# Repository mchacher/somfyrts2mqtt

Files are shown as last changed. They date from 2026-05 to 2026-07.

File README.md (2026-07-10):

# somfyrts2mqtt

A Somfy RTS to MQTT bridge running on an ESP32 + CC1101 transceiver. Plug it on your LAN, configure it once via a captive portal, and your Somfy RTS shutters and awnings become controllable from any MQTT-aware home automation system.

The MQTT layer follows the [Tasmota Shutter convention](https://tasmota.github.io/docs/Blinds-and-Shutters/) — `cmnd/<root>/<name>/{Open,Close,Stop,Position,…}` topics, `tele/<root>/SENSOR` aggregated telemetry, `tele/<root>/LWT` retained presence. Any client that already speaks Tasmota integrates out of the box :

- **[Sowel](https://docs.sowel.org)** via the [`sowel-plugin-somfy-rts`](https://github.com/mchacher/sowel-plugin-somfy-rts) plugin — the original target ; this bridge is a companion device for the Sowel home-automation engine
- **[Home Assistant](https://www.home-assistant.io/integrations/mqtt/)** via the MQTT Cover integration (see the sample YAML in [docs/mqtt-api.md](docs/mqtt-api.md#home-assistant))
- **OpenHAB**, **Node-RED**, **mosquitto_pub**, or any custom MQTT client

The bridge stays a "dumb" RF transponder à la Zigbee2MQTT : every home-automation rule lives upstream.

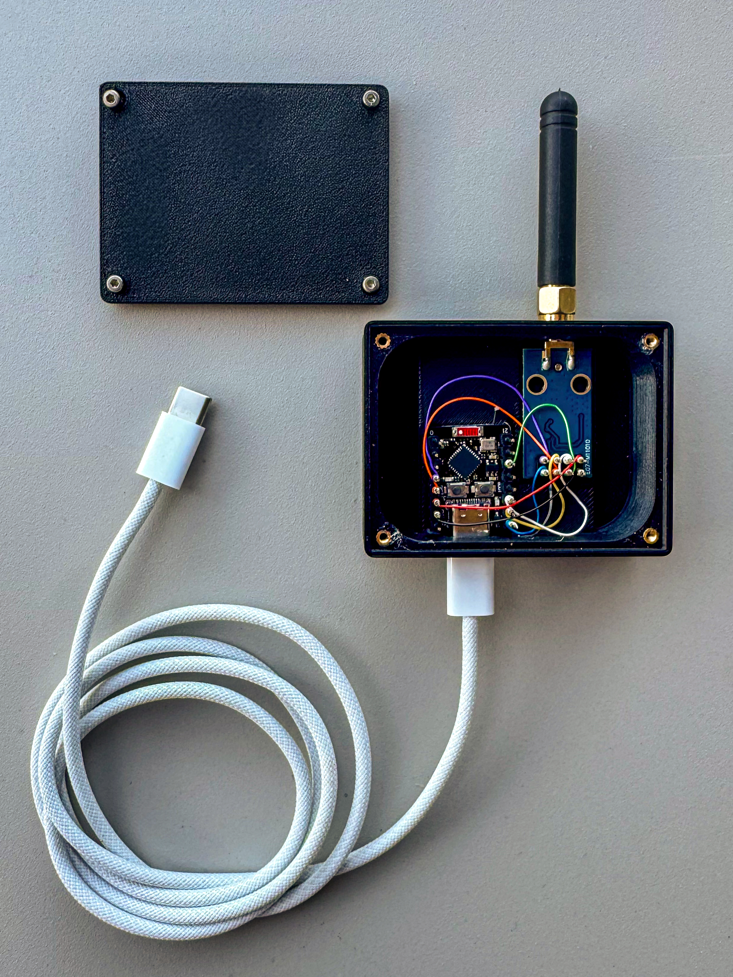
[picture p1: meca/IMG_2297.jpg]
Assembled device


The reference hardware is an ESP32-C3 Super Mini + CC1101 module wired together in a 3D-printed housing (FreeCAD source + STLs in [`meca/`](meca/)). Total cost ~10 €. The 7-wire ESP32 ↔ CC1101 interconnect can be done with regular soldering or with **30 AWG wire-wrap** — we strongly prefer wire-wrap for this kind of compact, point-to-point job : tighter, lower impedance, no rosin mess, and the connection looks far cleaner inside the housing. See [`meca/README.md`](meca/README.md#interconnect--wire-wrapping-recommended) for the why and the tool list, and [docs/hardware.md](docs/hardware.md) for the BoM and the pinout. If you would rather not solder anything, the firmware also supports the off-the-shelf **ESP32-S3 PICYBI Radio Remote** board (CC1101 already wired) — flash its `esp32-s3-picybi` binary instead.

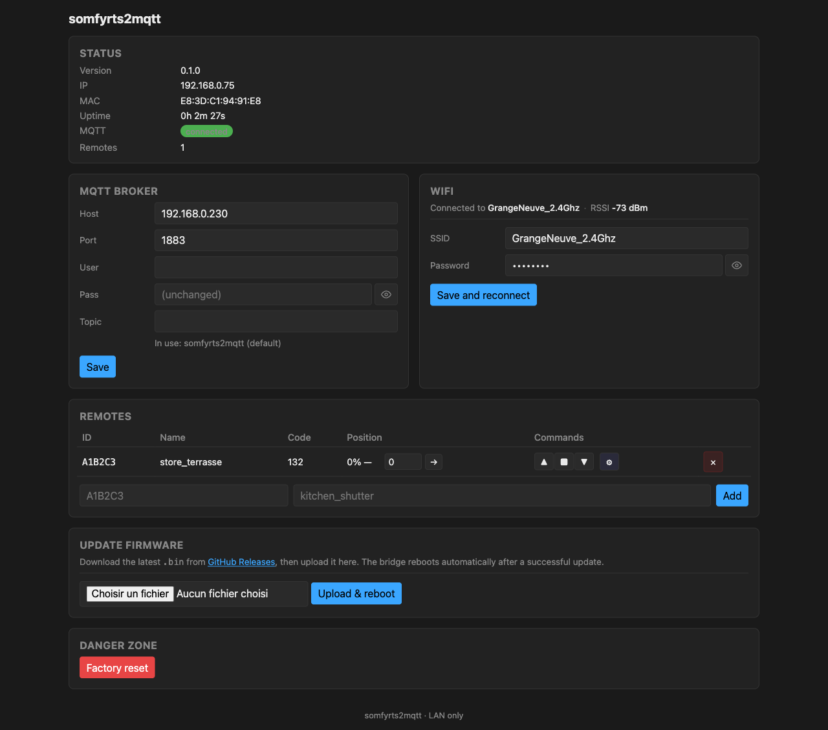
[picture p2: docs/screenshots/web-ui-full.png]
Web UI


## Features

- **Tasmota-style MQTT API** (Shutter subset) — `cmnd / stat / tele` topics, LWT, retained presence. Drop-in for any client that speaks Tasmota.
- **Time-based shutter position** (0-100 %) — calibrate Open / Close durations once, then send `Position 50` to move mid-travel.
- **Awning support** — per-remote Invert flag swaps Up / Down so a "store banne" reads as "100 % = extended".
- **Device types** — a remote can be a roller shutter (default) or a **sliding gate ("portail")**. A gate drops the time-based position and exposes Open / Close / Stop **plus a Toggle** — the dedicated Somfy RTS `Toggle` command (`0x0C`) that a single-button gate motor cycles on. Set per-remote in the admin UI ; the type is advertised on MQTT (`"Type":"gate"`) for the client to present accordingly. Additive and backward-compatible: existing shutters are untouched, no re-pairing.
- **WiFi captive portal commissioning** — fresh boot opens an AP, phone joins, enter SSID + password. No serial console required.
- **4-power-cycle AP recovery** — lost the LAN, wrong password, moved router ? Cycle the power 4 times within 5 s each → forces AP mode for re-commissioning.
- **mDNS** — reach the bridge as `somfyrts2mqtt.local`, no DHCP lease hunting.
- **Web admin UI** — embedded single-page, no external host. Configure broker, WiFi, durations, pair / erase remotes.
- **OTA updates** — one pre-built `firmware.bin` **per board** published with each tagged release on GitHub. The user uploads the one matching their board from the admin UI's *Update firmware* section ; the bridge validates the image, writes the second OTA slot, and reboots. A binary built for the wrong chip is rejected up front with a clear message, and a botched write is rolled back automatically by the dual-app partition scheme.

## Quickstart

### 1. Wire the CC1101

See [docs/hardware.md](docs/hardware.md) for the bill of materials, pinout, antenna, and power notes.

### 2. Flash the firmware

For the **first flash** (no firmware on the board yet), grab the pre-built `firmware.bin` **matching your board** from [the latest GitHub Release](https://github.com/mchacher/somfyrts2mqtt/releases/latest) — `…-esp32-c3-mini.bin` for the C3 Super Mini, `…-esp32-s3-picybi.bin` for the PICYBI ESP32-S3 — and upload it via `esptool`, or build from source :

```bash
git clone https://github.com/mchacher/somfyrts2mqtt.git
cd somfyrts2mqtt

# Build + upload (USB cable plugged in). Pick the env matching your board:
pio run -e esp32-c3-mini   -t upload -t monitor   # ESP32-C3 Super Mini
pio run -e esp32-s3-picybi -t upload -t monitor   # ESP32-S3 (PICYBI Radio Remote)
```

No code-side credentials needed — the firmware boots into a captive portal on first start.

Subsequent updates can be done **over WiFi without a USB cable** : download the new `.bin` from Releases, drop it in the admin UI's *Update firmware* section. See [docs/setup.md](docs/setup.md#updating-firmware-over-the-air).

### 3. Configure on first boot

The bridge advertises an open WiFi SSID `somfyrts2mqtt-<MAC>`. Connect with your phone, open `http://192.168.4.1`, enter your home WiFi credentials. The bridge reboots and joins your LAN.

See [docs/setup.md](docs/setup.md) for the full walkthrough.

### 4. Use the web UI

Open `http://somfyrts2mqtt.local/` (or the LAN IP shown in the Status block on the previous step). Configure your MQTT broker, add a Somfy remote (ID + name), calibrate Open / Close durations, and you are done.

See [docs/web-ui.md](docs/web-ui.md) for a section-by-section tour.

### 5. Talk MQTT

```bash
# Move kitchen blind fully open (100 %)
mosquitto_pub -h <broker> -t cmnd/somfyrts2mqtt/kitchen/Open -m ""

# Move halfway
mosquitto_pub -h <broker> -t cmnd/somfyrts2mqtt/kitchen/Position -m 50

# Tail telemetry
mosquitto_sub -h <broker> -t "tele/somfyrts2mqtt/#" -v
```

The Tasmota Shutter command set is documented in [docs/mqtt-api.md](docs/mqtt-api.md). A user-friendly Python CLI is shipped in [tools/mqtt-cli.py](tools/mqtt-cli.py).

## Documentation

| Page | Content |
|---|---|
| [docs/hardware.md](docs/hardware.md) | Bill of materials, ESP32 ↔ CC1101 wiring, antenna, power supply notes |
| [docs/setup.md](docs/setup.md) | Build, first flash, captive portal commissioning, factory reset, 4-power-cycle recovery |
| [docs/web-ui.md](docs/web-ui.md) | Section-by-section walkthrough with screenshots |
| [docs/mqtt-api.md](docs/mqtt-api.md) | Tasmota Shutter topic reference, payload examples, LWT, mqtt-cli.py |
| [docs/troubleshooting.md](docs/troubleshooting.md) | Common pitfalls (AUTH_EXPIRE on C3, dead CC1101, mDNS resolution, etc.) |
| [docs/releasing.md](docs/releasing.md) | Maintainer-side : how to cut a release, versioning, PR labels for the auto-generated notes |
| [CLAUDE.md](CLAUDE.md) | Project conventions, code style, contribution notes |
| [specs/](specs/) | Per-iteration design notes (specs / architecture / plan) |

## Project layout

```
somfyrts2mqtt/
├── src/, include/         Firmware source (Arduino-ESP32, C++17)
├── lib/                   Vendored libraries (none currently, libs via PlatformIO)
├── test/                  Native (host) unit tests (Unity)
├── tools/                 Helper scripts (mqtt-cli.py, requirements.txt)
├── specs/                 Per-iteration design notes
├── docs/                  This documentation
└── .github/workflows/     CI : build + cppcheck + native tests + CodeQL + Dependabot
```

## Status

Active development. Validated on the ESP32-C3 Super Mini (reference DIY build) and the ESP32-S3 PICYBI Radio Remote (off-the-shelf, CC1101 pre-wired). Each ships its own release binary; see spec `021-multiboard-ota-safety`. Spec roadmap : [specs/](specs/).

## License

**GNU GPL v3.0** — see [LICENSE](LICENSE). Aligns with Tasmota (whose Shutter MQTT protocol this bridge speaks), keeps every downstream fork open-source.

Third-party libraries shipped at runtime are listed in [THIRD_PARTY_LICENSES.md](THIRD_PARTY_LICENSES.md) with their respective licenses (mostly MIT, a few LGPL-3.0 and Apache 2.0). All are GPL-3.0 compatible.

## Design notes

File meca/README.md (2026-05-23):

# Enclosure

3D-printable housing for the bridge. Holds the ESP32 + CC1101 module + SMA antenna connector with the USB-C cable threaded out the side.

## Renders

| Housing (open) | Cover | Assembled |
|---|---|---|
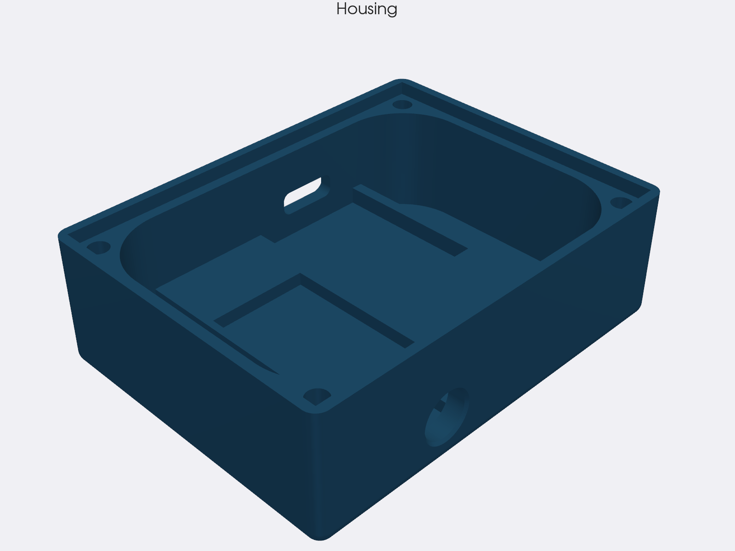
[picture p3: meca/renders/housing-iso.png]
Housing
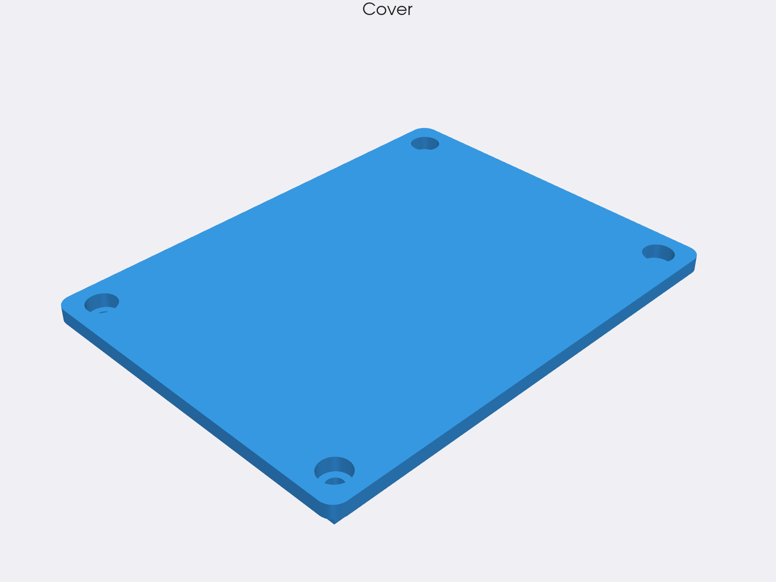
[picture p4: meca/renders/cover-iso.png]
Cover
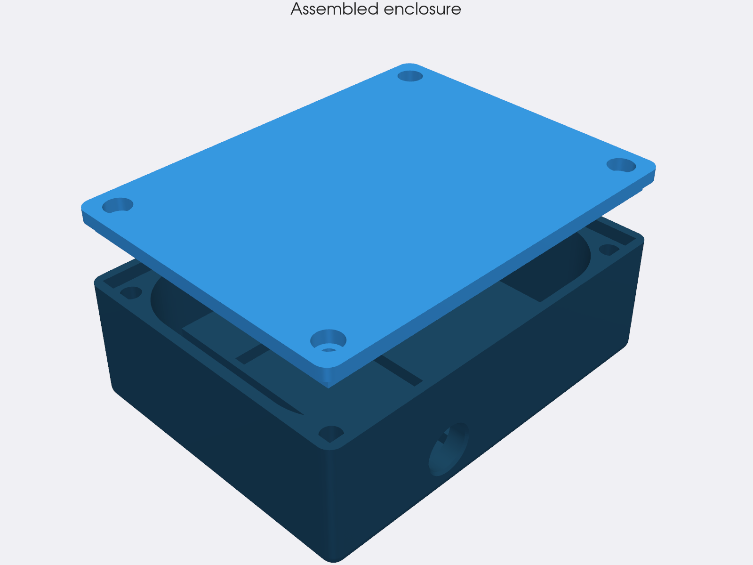
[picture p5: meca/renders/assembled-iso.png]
Assembled
|  |  |  |

The 4 countersunk corner holes line up with the heat-set inserts pressed into the housing posts ; the SMA bulkhead notch is on the back wall, the USB-C cutout on the side. Renders are generated headless from the STL files by [`scripts/render_meca.py`](../scripts/render_meca.py) (PyVista / VTK).

## Photo

Assembled device with housing open

## Files

| File | Purpose |
|---|---|
| `somfyrts2mqtt_housing.FCStd` | FreeCAD source -- modify here, re-export the STLs |
| `somfyrts2mqtt_housing-box_housing.stl` | Main box, print 1× |
| `somfyrts2mqtt_housing-box_cover.stl` | Lid, print 1× |
| `IMG_2297.jpg` | Photo of the assembled device with the lid removed, USB-C cable and SMA whip antenna attached |

## Interconnect : wire-wrapping recommended

Dupont jumpers work but rattle around in a 3D-printed box and add 1-2 cm of unnecessary loop -- enough to degrade SPI signal integrity on borderline CC1101 clones (see [docs/troubleshooting.md](../docs/troubleshooting.md#cc1101-not-responding)). The cleanest interconnect between the ESP32 and the CC1101 inside this housing is **wire-wrapping** with 30 AWG wire :

- 7 wires (SCK, MISO, MOSI, CSN, GDO0, VCC, GND), straight, short (< 3 cm).
- Wrap the wire around the pin header posts on both boards. No solder needed at first ; once you're sure the wiring works, dab a tiny bit of solder on each wrap for permanence.
- Tighter, lighter, lower-impedance than Dupont. The photo above shows this style.

Wire-wrap tool : a 30 AWG / Vector P184 wrap tool costs ~5 €. The 30 AWG enameled / silver-plated wire comes on a spool for a couple of euros.

## Mechanical bill of materials

In addition to the [electronic BoM](../docs/hardware.md#bill-of-materials) you need :

| Part | Qty | Notes |
|---|---|---|
| **M2 heat-set brass insert** | 4 | Pressed into the 4 corner posts of the housing with a soldering iron at ~200 °C. The cover then bolts onto these inserts |
| **M2 screw, ~6 mm long** | 4 | Holds the cover onto the housing. Cap-head looks cleaner ; flat-head is fine |

The SMA pigtail and the 433 MHz whip antenna ship with most CC1101 modules, so they are not listed here -- the housing just has a notch for the SMA flange.

## Print settings

Tested with PLA on a Bambu Lab printer ; defaults are forgiving :

| Setting | Value |
|---|---|
| Material | PLA or PETG (PETG if the bridge sits in direct sunlight / heat) |
| Layer height | 0.2 mm |
| Infill | 20 % gyroid or grid |
| Perimeters | 3 |
| Top / bottom layers | 4 |
| Supports | None required (the design is print-orientation-friendly) |
| Brim | 5 mm for the housing if you have warping issues ; not needed for the lid |
| Print orientation | Housing : opening up. Lid : flat |

## Modifying the design

Open `somfyrts2mqtt_housing.FCStd` in [FreeCAD](https://www.freecad.org/) ≥ 0.21. The model is parametric -- key dimensions live in a spreadsheet at the top of the tree. After editing, re-export both STLs from the `Mesh` workbench.

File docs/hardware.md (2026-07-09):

# Hardware

The bridge needs three things : an ESP32 MCU, a CC1101 sub-GHz transceiver, and a 433 MHz antenna. Total cost is around 5-10 €.

## Bill of materials

| Item | Notes |
|---|---|
| **ESP32-C3 Super Mini** _or_ **ESP32-S3 (PICYBI Radio Remote)** | Two supported boards. The C3 Super Mini is the reference DIY build (compact, native USB-CDC, 3.3 V LDO from USB). The PICYBI is an off-the-shelf ESP32-S3 board with the CC1101 already wired — nothing to solder. Each has its own pinout (below) and its own release binary |
| **CC1101 module** at 433 MHz, 26 MHz crystal | Any clone works ; some have flaky SPI -- see [troubleshooting](troubleshooting.md). Verify the crystal frequency on the module label : 27 MHz boards exist and need a code tweak |
| **17.3 cm of solid copper wire** | Quarter-wave at 433.42 MHz. Soldered to the CC1101 `ANT` pad. Skip if the board already has a spring antenna or an SMA connector |
| **Dupont jumper wires** | 7 wires : SCK, MISO, MOSI, CSN, GDO0, VCC, GND. Keep short (≤ 5 cm) to avoid SPI signal degradation |
| **(Optional) 100 nF + 100 µF decoupling capacitors** | Across the CC1101 VCC / GND, close to the module. Helps borderline modules ; see [troubleshooting](troubleshooting.md) |

## Wiring — ESP32-C3 Super Mini

| CC1101 pin | ESP32-C3 GPIO | Notes |
|---|---|---|
| VCC | 3V3 | Do **not** use 5V -- CC1101 is 3.3 V only |
| GND | GND | Shared ground |
| SCK | GPIO 4 | SPI clock |
| MISO | GPIO 5 | SPI data in |
| MOSI | GPIO 6 | SPI data out |
| CSN | GPIO 7 | Chip select |
| GDO0 | GPIO 10 | TX data line (modulation input) |
| GDO2 | GPIO 3 | Optional, RX / sniffing (not used in current firmware) |

Strapping pins to avoid on the C3 : GPIO 2, 8, 9.

```
ESP32-C3 Super Mini                 CC1101 module
                   ┌─────────────┐
              3V3  │ ●           │
              GND  │ ●           │
              ...                ▶ VCC  (3.3 V)
              GPIO 4   ────────────▶ SCK
              GPIO 5   ◀────────────  MISO
              GPIO 6   ────────────▶ MOSI
              GPIO 7   ────────────▶ CSN
              GPIO 10  ────────────▶ GDO0  (TX)
              GPIO 3   ◀────────────  GDO2  (RX, optional)
              GND      ────────────▶ GND
                   │             │
                   └─────────────┘
                          ANT  ───────  17.3 cm wire antenna
```

## Wiring — ESP32-S3 (PICYBI Radio Remote)

This board already has the CC1101 wired to the S3, so there is nothing to
solder — this table just documents the mapping the firmware expects
(`pio run -e esp32-s3-picybi`). Flash with the `esp32-s3-picybi` binary.

| CC1101 pin | ESP32-S3 GPIO | Notes |
|---|---|---|
| VCC | 3V3 | 3.3 V only |
| GND | GND | Shared ground |
| SCK | GPIO 12 | SPI clock |
| MISO | GPIO 13 | SPI data in |
| MOSI | GPIO 11 | SPI data out |
| CSN | GPIO 10 | Chip select |
| GDO0 | GPIO 8 | TX data line (modulation input) |
| GDO2 | GPIO 9 | Optional, RX / sniffing (not used in current firmware) |

Strapping pins on the S3 are GPIO 0, 3, 45, 46 — so GDO0/GDO2 on GPIO 8/9 are
fine here (they are *not* strapping on the S3, unlike the C3). The board uses
the native USB-Serial/JTAG for flashing and serial; the boot log over USB is
lost to CDC re-enumeration unless the firmware is built with `-DWAIT_FOR_SERIAL`
(dev-only, off by default).

## Antenna

A 17.3 cm length of solid copper wire (quarter-wave at 433.42 MHz) gives reliable whole-house coverage. Solder one end to the CC1101 `ANT` pad, leave the rest straight or in a vertical helix. Keep the wire away from the ESP32 metal can and any large metal surface.

If the board already has a spring antenna or an SMA connector, skip the wire. SMA + a real antenna gives the best range.

## Power supply

USB power from a 5 V / 2 A wall adapter is the recommended setup. Avoid :

- **Laptop USB hubs without external power** — they often sag below 4.6 V under load, which propagates to a sagging 3.3 V on the ESP32 LDO, which propagates to flaky WiFi and CC1101 SPI errors.
- **Long / thin USB cables** — voltage drops up to 0.5 V on the supply rail during WiFi TX bursts.

A 100 µF electrolytic cap across the CC1101 VCC / GND can rescue borderline setups. See [troubleshooting](troubleshooting.md).

## ESP32-C3 Super Mini specific note

The C3 Super Mini PA is miscalibrated above ~15 dBm on some boards. The firmware clamps `WiFi.setTxPower()` to 8.5 dBm explicitly to avoid AUTH_EXPIRE loops on certain APs (notably Freebox). This is automatic ; no user action required. See [troubleshooting](troubleshooting.md) for the full story.

## Enclosure (3D-printable)

A FreeCAD design + STLs for a small printed housing live in [`meca/`](../meca/). The box holds the ESP32 + CC1101 with an SMA bulkhead on top for an external whip antenna and a USB-C cutout on the side.

Assembled device, lid open

Additional parts beyond the BoM above :

- **4 × M2 heat-set brass inserts** (pressed into the housing posts with a soldering iron)
- **4 × M2 screws** (~6 mm) to hold the lid onto the inserts

Full file inventory, print settings, and assembly notes : [`meca/README.md`](../meca/README.md).

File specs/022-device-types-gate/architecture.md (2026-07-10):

# Architecture 022 — RTS device types (foundation + Gate)

## Touched modules

| File | Change |
| --- | --- |
| `include/device_profile.h` | **New.** Pure header: `DeviceType` + `uses_position`/`name`/`from_u8` + `SOMFY_TOGGLE = 0x0C`. |
| `include/nvs_store.h` / `.cpp`| `Remote.device_type` + `set_device_type` + `r.<hex>.typ` key; SCHEMA stays 1. |
| `include/mqtt.h` | `Command::Toggle` (+ `command_to_str`); additive `Type` in `publish_shutter_state`. |
| `src/mqtt.cpp` | `Toggle` cmnd verb; emit `"Type"` in SENSOR + stat **only when type != Shutter**. |
| `src/orchestrator.cpp` | Button resolution (Toggle → `0x0C`); Gate = no state; `tick`/`set_position`/durations guard non-positional. |
| `src/web_ui.cpp` | Type selector; Gate command cell = Open/Stop/Close + Toggle button, blind state; `/api/remotes/<id>/type` setter + `.../toggle` command. |
| `test/test_device_profile/`  | **New.** Native tests for the profile mapping, `from_u8`, `valid_toggle_button`. |
| docs | `docs/mqtt-api.md`, `docs/web-ui.md`, `README.md`, `CLAUDE.md`. |

## Decisions

**A Gate uses the dedicated Somfy RTS `Toggle` command `0x0C`.** A single-button
gate motor cycles open/stop/close/stop on this one command — it is its own RTS
button code, distinct from Up/Down/My (which do those actions separately). Source:
rstrouse/ESPSomfy-RTS (`somfy_commands::Toggle = 0xC`; `isToggle()` for the
`*gate1`/`garage1` single-button shade types). The Gate exposes **Open / Close /
Stop *and* Toggle** so both a distinct motor and a single-button one are covered.
*Rejected drafts:* a binary Open/Close/Stop cover (fabricates a state the bridge
cannot know), and a configurable Up/My/Down toggle button (those are not a toggle
— they do open/stop/close; the real toggle is 0x0C). It tracks **no position**
(a gate is blind). `rf::send_somfy` already takes a raw button byte and the lib's
`buildFrame` shifts any 4-bit value into place, so `0x0C` emits with no extra work.

**One orthogonal axis, default = Shutter, read-with-default.** A missing
`r.<hex>.typ` reads 0 = Shutter → today's exact behaviour, **zero migration**.
**`SCHEMA_VERSION` deliberately stays 1** (as iter 014): `init()` treats any
stored `schema != SCHEMA_VERSION` as "refusing to operate", so a bump would
brick access to every remote on an upgraded box. Additive keys need no bump, and
the motor never needs re-pairing (remote_id + rolling_code are untouched).

**`device_profile` stays a pure header** (no NVS/MQTT/Arduino dep), like
`shutter_state.h` / `ota_guard.h`. `nvs_store` stores type/button as raw bytes;
the orchestrator/mqtt/web layers interpret via `device_profile`.

**MQTT stays a strict superset; `Type` is emitted only for non-Shutter** →
a pure-shutter deployment is byte-identical on the wire. The bridge emits the
hint + the `Toggle` verb; mapping to a Sowel `gate` is the plugin's job (later).

## Flow (handle_command)

```
handle_command(id, cmd):
  remote = get_remote(id)                        # carries device_type + toggle_button
  if cmd == Toggle: button = SOMFY_TOGGLE (0x0C)                          # no invert
  else:             button = command_to_button(apply_invert(cmd))
  if button == 0: drop
  persist rolling_code (before emit)
  rf::send_somfy(id, next_code, button, repeat)   # Toggle repeat = 1
  if uses_position(profile):                       # Shutter -> iter-014 machine, verbatim
      run time-based state machine
  # else (Gate): blind -> no position/direction/state update
  publish_stat(remote, rt)                         # stat/SENSOR gain "Type" iff non-Shutter
  publish_sensor_aggregated()
```

RF emission, rolling-code persist-before-emit, and `invert` (for non-toggle
commands) are shared and unchanged across every type. `tick()` skips
non-positional remotes.

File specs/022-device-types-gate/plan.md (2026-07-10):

# Plan 022 — RTS device types (foundation + Gate)

## Steps

1. **Branch** `feat/device-types-gate` from `main`.
2. **`include/device_profile.h`** (new, pure): `DeviceType {Shutter=0, Gate=1}`;
   `uses_position` (true only for Shutter); `name` ("shutter"/"gate"); `from_u8`
   (unknown ⇒ Shutter); `SOMFY_TOGGLE = 0x0C` (dedicated Somfy Toggle command).
3. **`nvs_store`**: `Remote.device_type`; `remote_type_key` (".typ"); seed in
   `add_remote` (type 0); read in `get_remote`/`list_remotes`; remove on delete;
   `set_device_type`. **SCHEMA stays 1.**
4. **`mqtt`**: add `Command::Toggle` (+ `command_to_str`); a `Toggle` cmnd verb;
   emit `"Type"` in SENSOR + stat guarded by `type != Shutter`.
5. **`orchestrator`**: resolve the button (Toggle → `0x0C`, no invert; else
   mapped/inverted). Shutter keeps the state machine; a Gate updates no runtime
   state. `tick()` skips non-positional; `set_position`/duration setters
   warn+ignore for a Gate.
6. **`web_ui`** (admin portal — extra care): Type `<select>`; the Gate command
   cell shows **Open / Stop / Close + a Toggle (🔄)** button and a blind "—"
   state; duration/position/invert hide for a Gate. `/api/remotes/<id>/toggle`
   command + `/type/<n>` setter; `/api/remotes` JSON gains `device_type`.
7. **Tests**: `test/test_device_profile/` — mapping, `uses_position`, `from_u8`,
   `SOMFY_TOGGLE`. The `handle_command` Toggle path is HW-validated
   (`test_orchestrator` only unit-tests the pure helpers — end-to-end needs
   NVS/MQTT/RF).
8. **Docs** — `docs/mqtt-api.md` (Toggle verb + gate semantics + `Type`),
   `docs/web-ui.md` (Type + Toggle button), `README.md`, `CLAUDE.md`.
9. **Build / check / test** — `pio run` both envs, `pio check` both, `pio test
   -e native` green.
10. **Flash + HW test** on a bench gate (below).
11. **PR** on `mchacher/somfyrts2mqtt` (revises PR #36); link this spec.

## Test plan (HW)

- **Non-regression (critical)**: an existing Shutter remote — Open/Close/Stop +
  Position N still work; its SENSOR JSON is unchanged (no `Type`). No re-pairing.
- **Gate toggle**: set a remote to `Gate`; the command cell shows Open / Stop /
  Close + a **Toggle** button. Clicking **Toggle** (or `cmnd/.../Toggle`) emits
  the Somfy Toggle command `0x0C` → the gate advances one step (open → stop →
  close → stop). The RF log shows `button=0x0C`. Open/Close/Stop still emit
  Up/Down/My.
- **No re-pairing**: after OTA from v0.4.0 + switching the remote to Gate, the
  already-paired motor responds (remote_id + rolling_code preserved).
- **Persistence**: reboot → type + toggle button survive; other remotes stay Shutter.

## Edge cases
- [ ] Unknown/forward `device_type` ⇒ `from_u8` ⇒ Shutter (no crash).
- [ ] `Toggle` sent to a Shutter ⇒ emits `0x0C` too (harmless; motor ignores it).
- [ ] `Position`/`OpenDuration` sent to a Gate ⇒ warn + ignore.
- [ ] SENSOR buffer still fits with the extra `Type` field.

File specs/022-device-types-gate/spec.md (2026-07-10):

# 022 — RTS device types (foundation + Gate)

## Goal
Let a remote declare what kind of RTS equipment it drives, so the bridge can
behave correctly beyond roller shutters — starting with a **sliding gate
("portail coulissant")** — **without changing anything for existing remotes or
the current MQTT integration**. Introduce one new orthogonal axis
(`device_type`, default `Shutter`) plus the first non-shutter type.

## Background
Today every remote is modelled as a Tasmota **Shutter** (time-based position
0-100 + durations + `invert`). A Somfy RTS gate motor in **sequential mode**
cycles open → stop → close → stop on a **single repeated RTS button** — the
motor does the sequencing, the remote just re-sends one button. It has no
position and no state feedback (RTS is blind). So a gate is not a cover with
distinct Open/Close/Stop; it is a **single-button toggle**. We want a
type-aware bridge that stays a "dumb" transponder and is strictly additive: a
legacy all-shutter deployment must be byte-for-byte identical in RF, NVS and MQTT.

## Scope

In scope (firmware only):
- **`include/device_profile.h`** — new pure header: `enum class DeviceType :
  uint8_t { Shutter = 0, Gate = 1 }`, `uses_position()`, `name()`, `from_u8()`
  (unknown → `Shutter`, defensive), plus `SOMFY_TOGGLE = 0x0C` (the dedicated
  Somfy RTS Toggle command). Native-testable.
- **NVS** (`nvs_store`) — per-remote `r.<hex>.typ` (device type, default 0 =
  Shutter) key + `Remote.device_type` + `set_device_type()`. A missing key reads
  0 → **existing remotes read as Shutter automatically**. **`SCHEMA_VERSION`
  stays 1**: an additive key needs no bump, and bumping would trip `init()`'s
  "unknown schema → refusing to operate" on a box upgraded from v0.4.0, wiping
  access to every stored remote.
- **Command** — new `mqtt::Command::Toggle`: emit the Somfy RTS Toggle command
  `0x0C` (no `invert`; it is its own button code).
- **Orchestrator** — `handle_command` resolves the button (`Toggle` → `0x0C`;
  else the mapped/inverted command). `Shutter` keeps today's time-based state
  machine **verbatim**; a `Gate` tracks **no position/direction/state** and is
  skipped by the 1 Hz `tick()`. `set_position`/duration setters warn-and-ignore
  for a Gate.
- **MQTT** — new `cmnd/<root>/<name>/Toggle` verb (Open/Close/Stop already
  exist). Additive `"Type":"gate"` in the SENSOR object and `stat` JSON, emitted
  **only for non-Shutter** remotes.
- **Web UI (admin portal)** — per-remote **Type** selector; a Gate command cell
  shows **Open / Stop / Close** plus a **Toggle** (🔄) button, and a blind "—"
  state (no position); the duration/position/invert calibration hides for a Gate.
- **Tests** — native `test_device_profile` (mapping, `from_u8`, `SOMFY_TOGGLE`).
- **Docs** — device type, the `Toggle` verb + `Type` hint contract, gate notes.

Out of scope:
- **No Sowel changes.** The bridge only emits the `Type` hint + `Toggle` verb;
  presenting a gate as a Sowel `gate` (device_class, state) is a separate
  Sowel-plugin task. A gate stays operable via the current plugin meanwhile.
- A *distinct* Open/Close/Stop gate (non-sequential motor) — that fits the
  Shutter type; not modelled as a separate device here.
- Other types (`Pulse`/`OnOff`) — later increments on the same foundation.
- No `invert` change (orthogonal modifier for positional types).

## Acceptance criteria
- [ ] Existing all-shutter deployment: RF frames, NVS keys and SENSOR/stat JSON
      are unchanged (no `Type` field when every remote is Shutter).
- [ ] A remote set to `Gate`: the UI command cell shows Open / Stop / Close + a
      **Toggle** button; `Toggle` emits the Somfy Toggle command `0x0C`; SENSOR
      reports `"Type":"gate"`; no position, no auto-stop tick; calibration hidden.
- [ ] `cmnd/<root>/<name>/Toggle` emits button `0x0C` (verified on the RF log /
      by the gate cycling); Open/Close/Stop still emit Up/Down/My.
- [ ] `device_type` defaults to Shutter for every pre-existing NVS remote (no
      re-pairing).
- [ ] `SCHEMA_VERSION` stays 1; a box OTA-upgraded from v0.4.0 keeps all its
      remotes (init() never hits "refusing to operate"). **No re-pairing of the
      motor** (remote_id + rolling_code untouched).
- [ ] `pio run` clean on both envs, `pio check` clean, `pio test -e native`
      green incl. `test_device_profile`.
- [ ] CI green on the PR.

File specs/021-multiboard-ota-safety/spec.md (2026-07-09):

# 021 — Multi-board build + OTA safety (ESP32-S3 PICYBI)

## Goal
Add the ESP32-S3 "PICYBI Radio Remote" as a second supported board (its own
CC1101 pinout + PlatformIO env), and make the build / release / OTA pipeline
safe now that more than one firmware binary exists — so a user can never brick
or silently mis-flash a board by uploading the wrong `.bin` over WebOTA.

## Background
The pinout and chip target are compile-time (`include/config.h`, selected by
`CONFIG_IDF_TARGET_*`). A C3 binary and an S3 binary are therefore not
interchangeable: different ISA (RISC-V vs Xtensa), different bootloader,
different GPIOs. Today `release.yml` ships a single `esp32-c3-mini` binary and
the WebOTA handler validates only the embedded MD5 (integrity), not that the
image matches the running board. A wrong-chip image is caught by the 2nd-stage
bootloader (`chip_id` mismatch → dual-app rollback, no brick) but the user only
sees a confusing silent revert. We want an explicit, early rejection and a
release that actually offers the right binary per board.

## Scope

In scope:
- `include/config.h`: add the `#elif defined(CONFIG_IDF_TARGET_ESP32S3)` CC1101
  pinout block (SCK12 / MISO13 / MOSI11 / CSN10 / GDO0 8 / GDO2 9); update the
  `#error` fallback to list both supported targets. *(already staged in the
  working tree from the validation flash)*
- `platformio.ini`: add `[env:esp32-s3-picybi]` (already staged) and add
  `-DFW_VARIANT=\"${PIOENV}\"` to `[firmware_base]` so every binary embeds its
  env name.
- `include/ota_guard.h`: new pure-logic header — parse the `chip_id` out of an
  `esp_image_header` prefix and expose the compile-time expected id. Native-
  testable, no Arduino/Update dependency.
- `src/web_ui.cpp`:
  - WebOTA upload handler rejects a wrong-chip image on the first chunk with
    HTTP 400 and a human message ("firmware targets ESP32-C3, this bridge is
    ESP32-S3"), before writing anything.
  - Status card displays `FW_VARIANT` next to `FW_VERSION`.
- `.github/workflows/ci.yml`: build + cppcheck **both** envs.
- `.github/workflows/release.yml`: build both envs, stage both bins as
  `somfyrts2mqtt-<ver>-<env>.bin`, update the release-notes body to tell the
  user to pick the binary matching their board.
- `src/main.cpp`: replace the temporary unconditional USB-CDC boot wait with a
  compile-guarded `#if defined(WAIT_FOR_SERIAL)` block (default off — no boot
  penalty in production; opt-in for native-USB serial debugging).
- `test/test_ota_header/`: native unit tests for `ota_guard` header parsing.
- Docs: `docs/hardware.md` (S3 board + pinout table), `docs/releasing.md`
  (two bins), `docs/setup.md` (per-board flash + OTA), `docs/web-ui.md`
  (Variant field + wrong-chip guard), `docs/troubleshooting.md` (S3 boot-log
  note), `README.md` (two supported boards / pick-your-binary), `CLAUDE.md`
  (re-add S3 to the hardware section; the "only C3" wording from spec 020 no
  longer holds).

Out of scope:
- Same-chip / different-pinout variant discrimination (a second S3 board with a
  different mapping). The `chip_id` guard does not cover it; a `FW_VARIANT`
  marker check in the image `esp_app_desc` is the follow-up if that ever ships.
- Auto-update / GitHub Releases polling, code-signing, HTTPS OTA — unchanged
  from spec 016 out-of-scope.
- Any C3-side behaviour change. The C3 binary stays functionally identical
  (only the new `FW_VARIANT` string and the CDC-wait guard differ, both inert
  at runtime on C3).

## Acceptance criteria
- [ ] `pio run -e esp32-c3-mini` and `pio run -e esp32-s3-picybi` both clean, zero warnings.
- [ ] `pio check` clean on both envs (high + medium).
- [ ] `pio test -e native` green, including new `test_ota_header` cases
      (valid C3 header, valid S3 header, bad magic, truncated buffer).
- [ ] HW (S3): upload the correct `esp32-s3-picybi` bin via WebOTA → progress
      100 %, reboot, Status card shows `esp32-s3-picybi <version>`.
- [ ] HW (S3): upload an `esp32-c3-mini` bin via WebOTA → rejected with 400 and
      a clear "wrong chip" message, board keeps running the old firmware (no reboot).
- [ ] CI builds both envs; a pushed `v*` tag produces a release listing
      `somfyrts2mqtt-<ver>-esp32-c3-mini.bin` **and**
      `somfyrts2mqtt-<ver>-esp32-s3-picybi.bin`.
- [ ] Production boot time on the C3 is unchanged (no CDC wait by default).
- [ ] CI green on the PR.

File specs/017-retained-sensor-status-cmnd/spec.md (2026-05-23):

# 017 — Retained SENSOR + bridge-wide `Status` cmnd

## Goal

A subscriber that connects to the broker **after** the bridge boot must still receive the current state of every paired remote. Today the bridge publishes `tele/<root>/SENSOR` on each motion / state-change but with `retained=false`, so a late subscriber sees nothing until something moves — which is exactly the case for the Sowel `sowel-plugin-somfy-rts` integration on a quiet morning.

This iter ships two complementary fixes :

- **Retained SENSOR** : every `publish_sensor_aggregated()` call uses `retained=true`. The broker keeps the latest snapshot ; any new subscriber to `tele/<root>/SENSOR` gets it immediately on subscribe.
- **`cmnd/<root>/Status`** : a bridge-wide command that forces a fresh SENSOR publish. Lets a client (Sowel plugin, mosquitto_pub, custom dashboard) explicitly trigger a resync — useful when the retained message went stale (broker restart without storage, broker storage cleared, manual resync button).

## Background

Today the only retained topic is `tele/<root>/LWT`. SENSOR is published live (1 Hz during motion + on each state change + once on MQTT connect) but never retained, so a fresh subscriber sees only LWT and stays blind until motion happens. Fix : retain the SENSOR snapshot, and let clients ask for a refresh on demand.

The bridge already implements a 4-segment cmnd subscription `cmnd/<root>/+/+` for per-remote commands. For a bridge-wide command we add a parallel 3-segment subscription `cmnd/<root>/Status`. Tasmota uses the same naming convention (`cmnd/<device>/Status`).

## Scope

**In scope**

- Pass `retained=true` to `s_client.publish()` inside `publish_sensor_aggregated()` (line 292 of `src/mqtt.cpp`). All 4 call sites (connect, on cmnd, on periodic, on calibration) inherit the fix automatically — no need to thread the flag through.
- Add a second subscription `cmnd/<root>/Status` after the existing `cmnd/<root>/+/+`.
- In `on_message`, detect the bridge-wide Status topic before the per-remote `parse_cmnd_topic` path. On match, call `publish_sensor_aggregated()`. Payload is ignored (Tasmota convention accepts a level digit ; we just always publish the aggregated view since that's all we have).
- Update `docs/mqtt-api.md` : document the retained nature of SENSOR + the new `cmnd/<root>/Status` verb.
- Bump tag to `v0.2.0`.

**Out of scope**

- Per-remote `cmnd/<root>/<name>/Status` (would just duplicate `stat/<root>/<name>` which already exists for ack). No need.
- Status sub-commands (Tasmota's `Status 0..13`). The bridge has one thing to report, no need to multiplex.
- Persisting retain across broker restarts (that's the broker's job ; mosquitto with `persistence true` keeps it).
- Republishing SENSOR on each Wi-Fi reconnect when MQTT was already up. Already covered by `try_connect()`.

## Acceptance

- [ ] `mosquitto_sub -h <broker> -t 'tele/<root>/#'` immediately receives the latest SENSOR after subscribing, even hours after the last motion.
- [ ] `mosquitto_pub -h <broker> -t 'cmnd/<root>/Status' -m ""` triggers a fresh SENSOR publish.
- [ ] The Sowel plugin `sowel-plugin-somfy-rts` discovers all paired remotes at `start()` without anyone moving anything.
- [ ] No regression on per-remote `cmnd/<root>/<name>/<verb>` dispatch.
- [ ] Native unit test for the topic discrimination logic (bridge-wide vs per-remote).
- [ ] Tag `v0.2.0` triggers the release workflow → both `.bin` artifacts attached to the GH Release.

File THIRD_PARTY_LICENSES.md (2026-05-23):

# Third-party licenses

The bridge firmware (this repository) is licensed under **GNU GPL v3.0** -- see [LICENSE](LICENSE).

At runtime, it links against the following third-party libraries (declared in [`platformio.ini`](platformio.ini) `lib_deps`). Each is redistributed unmodified by PlatformIO at build time ; full license text and source are available from each project's upstream repository.

| Library | Version constraint | License | Upstream |
|---|---|---|---|
| ArduinoJson | `^7.0.4` | MIT | <https://github.com/bblanchon/ArduinoJson> |
| PubSubClient | `^2.8` | MIT | <https://github.com/knolleary/pubsubclient> |
| SmartRC-CC1101-Driver-Lib | latest | MIT | <https://github.com/LSatan/SmartRC-CC1101-Driver-Lib> |
| Somfy_Remote_Lib | latest | Apache 2.0 | <https://github.com/Legion2/Somfy_Remote_Lib> |
| WiFiManager (tzapu) | `^2.0.17` | MIT | <https://github.com/tzapu/WiFiManager> |
| AsyncTCP (esp32async) | `^3.4.9` | LGPL-3.0 | <https://github.com/esp32async/AsyncTCP> |
| ESPAsyncWebServer (esp32async) | `^3.11.0` | LGPL-3.0 | <https://github.com/esp32async/ESPAsyncWebServer> |

The Arduino-ESP32 core (LGPL-2.1) and the ESP-IDF (Apache 2.0) are linked through the PlatformIO `espressif32` platform, also redistributed unmodified.

## License compatibility

GNU GPL v3.0 is compatible with all the licenses above :

- **MIT** → GPL : MIT is permissive, can be sublicensed under GPL.
- **Apache 2.0** → GPL : explicitly compatible since GPL-3.0 ([FSF list](https://www.gnu.org/licenses/license-list.html#apache2)).
- **LGPL-3.0** → GPL : the LGPL explicitly allows conversion to GPL.
- **LGPL-2.1** → GPL-3.0 : compatible via the LGPL's "any later version" clause.

LGPL-3.0 dependencies impose that the binary must remain relinkable against a different version of the library by the end user. Since this project is open-source and the `firmware.bin` published in [GitHub Releases](https://github.com/mchacher/somfyrts2mqtt/releases) is built from the source tagged in this same repository, anyone can rebuild and relink at will -- the LGPL obligation is satisfied by design.

## Acknowledgements

Special thanks to the maintainers of the libraries above. This bridge would not exist without their work, in particular :

- [@Legion2](https://github.com/Legion2) for the Somfy RTS protocol implementation that does the heavy lifting of frame building and bit-banging
- [@LSatan](https://github.com/LSatan) for the CC1101 driver
- [@tzapu](https://github.com/tzapu) for WiFiManager, which powers the captive portal commissioning flow
- [@esp32async](https://github.com/esp32async) for keeping AsyncTCP / ESPAsyncWebServer maintained
- [@knolleary](https://github.com/knolleary) and [@bblanchon](https://github.com/bblanchon) for the MQTT and JSON pillars of the embedded world

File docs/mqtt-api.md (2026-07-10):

# MQTT API

The bridge speaks the **Tasmota Shutter MQTT subset**, keyed by remote name (not by Tasmota's integer index). Most Tasmota / ESPHome / Home Assistant tools work out of the box.

## Topic structure

With `<root>` = the value of `mqtt.topic` from the admin UI (default `somfyrts2mqtt`) and `<name>` = a registered remote's name :

```
Commands (you publish to the bridge)
  cmnd/<root>/<name>/Open                ""          → move to 100 %
  cmnd/<root>/<name>/Close               ""          → move to 0 %
  cmnd/<root>/<name>/Stop                ""          → stop current motion
  cmnd/<root>/<name>/Position            0..100      → move to N %
  cmnd/<root>/<name>/OpenDuration        <seconds>   → set full-Open time
  cmnd/<root>/<name>/CloseDuration       <seconds>   → set full-Close time
  cmnd/<root>/<name>/SetPosition         0..100      → mark current position (no RF)
  cmnd/<root>/<name>/Toggle              ""          → Gate: emit the Somfy 80-bit Toggle frame (single-button cycle, since v0.5.0)
  cmnd/<root>/Status                     ""          → force a fresh SENSOR publish (since v0.2.0)

State (bridge publishes)
  tele/<root>/LWT                        "Online" | "Offline"   (retained + LWT)
  tele/<root>/SENSOR                     JSON, retained, on connect + every 1 s during motion + on state change
  stat/<root>/<name>                     JSON, ack after each cmnd
```

The bridge subscribes with two patterns : `cmnd/<root>/+/+` for per-remote commands (adding a new remote is a NVS operation, no re-subscribe needed), and `cmnd/<root>/Status` for the bridge-wide resync command.

**SENSOR is retained since v0.2.0.** A fresh subscriber to `tele/<root>/SENSOR` receives the latest snapshot of every paired remote immediately on subscribe — no need to wait for the next motion or to issue a Status command. Tools like the Sowel `sowel-plugin-somfy-rts` integration rely on this for discovery.

## Payloads

### `tele/<root>/SENSOR` (aggregated, retained, 1 Hz during motion)

```json
{
  "kitchen": {"Position": 45, "Direction": 1, "Target": 100},
  "bedroom": {"Position": 0,  "Direction": 0, "Target": 0},
  "driveway": {"Position": 0, "Direction": 0, "Target": 0, "Type": "gate"}
}
```

| Field | Range | Meaning |
|---|---|---|
| `Position` | 0..100 | Current estimated position. 0 = closed, 100 = open (or extended for awnings) |
| `Direction` | -1, 0, 1 | -1 closing, 0 idle, 1 opening (Tasmota convention) |
| `Target` | 0..100 | Destination of the current or last motion |
| `Type` | string | **Optional (iter 022).** Device type when it is *not* a shutter — currently `"gate"`. **Absent for shutters**, so a pure-shutter deployment is byte-identical to before. A gate is blind (no feedback): `Position`/`Direction`/`Target` are present but meaningless — ignore them for a gate. |

**Device types.** By default every remote is a roller shutter (time-based
position). A remote can be switched to another RTS equipment type in the admin
UI (Remotes → ⚙ → Type). A **Gate** ("portail coulissant") drops the time-based
position (a gate is blind — no feedback) and exposes **four** commands:
`Open` / `Close` / `Stop` (which emit Up / Down / My) **and** `Toggle`. The
Toggle is the Somfy single-button command — a dedicated **80-bit RTS frame**
(not a normal button byte), which the bridge encodes and transmits itself. A
single-button gate motor cycles open → stop → close → stop on `Toggle`;
`Open`/`Close`/`Stop` also work if the motor honours them separately. A gate advertises `"Type":"gate"` so a consumer
can present it as an HA `cover` with `device_class: gate`. The bridge only emits
the hint + the verbs; the device-class mapping is the client's job.

### `stat/<root>/<name>` (per-cmnd ack)

After Open / Close / Stop / Position / SetPosition :

```json
{"Position": 45, "Direction": 1, "Target": 100}
```

After OpenDuration / CloseDuration :

```json
{"OpenDuration": 18.5, "CloseDuration": 20.0}
```

On error (e.g. uncalibrated remote receives a `Position 50`) :

```json
{"error": "not calibrated"}
```

### `tele/<root>/LWT`

| Payload | When |
|---|---|
| `Online` | Published with retain=true immediately after connecting to the broker |
| `Offline` | Published by the broker via the MQTT Will mechanism when the bridge disconnects ungracefully ; or by the bridge with retain=true right before a planned disconnect |

## Examples (mosquitto_pub / sub)

```bash
# Move kitchen shutter all the way up
mosquitto_pub -h 192.168.0.230 -t cmnd/somfyrts2mqtt/kitchen/Open -m ""

# Set kitchen Open duration to 18 s
mosquitto_pub -h 192.168.0.230 -t cmnd/somfyrts2mqtt/kitchen/OpenDuration -m 18

# Move kitchen to 50 % (motor moves, bridge auto-stops near 50)
mosquitto_pub -h 192.168.0.230 -t cmnd/somfyrts2mqtt/kitchen/Position -m 50

# Mark kitchen as currently at 30 % (e.g. you used a physical remote ; resync)
mosquitto_pub -h 192.168.0.230 -t cmnd/somfyrts2mqtt/kitchen/SetPosition -m 30

# Force the bridge to republish SENSOR right now (since v0.2.0)
mosquitto_pub -h 192.168.0.230 -t cmnd/somfyrts2mqtt/Status -m ""

# Watch every state change
mosquitto_sub -h 192.168.0.230 -t "tele/somfyrts2mqtt/#" -v
mosquitto_sub -h 192.168.0.230 -t "stat/somfyrts2mqtt/#" -v
```

## Python CLI

A friendly wrapper sits in [`tools/mqtt-cli.py`](../tools/mqtt-cli.py). It uses `paho-mqtt` and a per-tools venv (kept out of git).

```bash
# One-time setup
python3 -m venv tools/.venv
tools/.venv/bin/pip install -r tools/requirements.txt

# Configure once via env
export MQTT_BROKER=192.168.0.230
export MQTT_ROOT=somfyrts2mqtt

# Then drive the bridge in one-liners
tools/.venv/bin/python tools/mqtt-cli.py open kitchen
tools/.venv/bin/python tools/mqtt-cli.py position kitchen 50
tools/.venv/bin/python tools/mqtt-cli.py open-dur kitchen 18.5
tools/.venv/bin/python tools/mqtt-cli.py watch           # live-tail tele + stat
tools/.venv/bin/python tools/mqtt-cli.py list            # quick table of all shutters
```

`tools/mqtt-cli.py --help` lists every subcommand.

## Home Assistant

Auto-discovery via Tasmota Discovery is not implemented yet (planned for a future iter). For now, declare each shutter manually in `configuration.yaml` :

```yaml
mqtt:
  cover:
    - name: "Kitchen shutter"
      command_topic: cmnd/somfyrts2mqtt/kitchen/Position
      position_topic: tele/somfyrts2mqtt/SENSOR
      position_template: "{{ value_json.kitchen.Position }}"
      set_position_topic: cmnd/somfyrts2mqtt/kitchen/Position
      payload_open:  "100"
      payload_close: "0"
      payload_stop:  ""    # use a Stop helper or a service instead
      position_open: 100
      position_closed: 0
      optimistic: false
      availability:
        - topic: tele/somfyrts2mqtt/LWT
          payload_available: Online
          payload_not_available: Offline
```

## Multi-bridge

If you run two bridges on the same broker, set distinct **Topic** values in each one's admin UI (e.g. `somfy-rdc` and `somfy-etage`). They share the broker but their topics never collide.

The MQTT client_id is derived from the Topic, so two bridges with the same Topic would kick each other from the broker (connect / disconnect ping-pong). Use unique Topics for each bridge.

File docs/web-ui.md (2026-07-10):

# Web UI walkthrough

The bridge embeds a single-page admin UI on port 80, no external dependencies. Open `http://somfyrts2mqtt.local/` (preferred) or the LAN IP shown in your router.

Default view

The page has four cards : **Status**, **MQTT broker**, **WiFi**, **Remotes**, plus a **Danger zone** row at the bottom.

## Status

Read-only summary of the bridge.

| Field | Meaning |
|---|---|
| Version | Firmware version baked at build time |
| Variant | Board/build the firmware was compiled for (`esp32-c3-mini` or `esp32-s3-picybi`). Tells you which release `.bin` to pick for OTA — the two are not interchangeable |
| IP | DHCP-assigned LAN address. Useful when mDNS does not resolve (some Linux / Android stacks) |
| MAC | Chip MAC. Last 6 hex are reused as the AP SSID suffix for commissioning |
| Uptime | Time since last boot |
| MQTT | Pill, green when connected to the broker, red otherwise |
| Remotes | Count of registered virtual remotes |

The Status card refreshes every 5 seconds.

## MQTT broker

Editable form. Same fields as any Tasmota / ESPHome config :

| Field | Notes |
|---|---|
| **Host** | Broker hostname or IP. No `mqtt://` prefix |
| **Port** | TCP port. 1883 for plain, 8883 for TLS (TLS not yet supported) |
| **User** / **Pass** | Optional. Empty Pass means "keep current" — leave empty when changing User but keeping the password |
| **Topic** | Tasmota-style root topic. Empty = default `somfyrts2mqtt`. Set distinct values if you run multiple bridges on the same broker |

The `In use:` line below the Topic field shows the active root the bridge currently publishes / subscribes against. Useful when the Topic was left empty — confirms which default was picked.

Click **Save** to persist. The bridge reconnects with the new settings ; the Status pill should flip back to green within a few seconds.

## WiFi

Editable WiFi credentials. Top line shows the current connection : `Connected to <SSID> · RSSI <dBm>`.

| Field | Notes |
|---|---|
| **SSID** | Pre-filled with the current network. Edit to switch networks |
| **Password** | `(unchanged if SSID matches current)` placeholder ; leave empty to keep the existing one. Eye toggle to reveal what you typed |

Click **Save and reconnect** to persist + restart. The bridge picks up the new credentials after the next boot.

To roll over to a network the bridge cannot currently reach, use the [4-power-cycle recovery](setup.md#reconfigure-wifi-without-re-flashing) instead — same form, exposed via the captive portal.

## Remotes

The heart of the bridge. Each row is a virtual Somfy remote that you previously paired with a motor.

Compact view shows only the columns needed for daily operation : **ID**, **Name**, **Code** (rolling code), **Position** (with a `Set` input), **Commands** (Up / Stop / Down + a ⚙ gear).

Click the ⚙ gear on a row to expand the **Setup** sub-row :

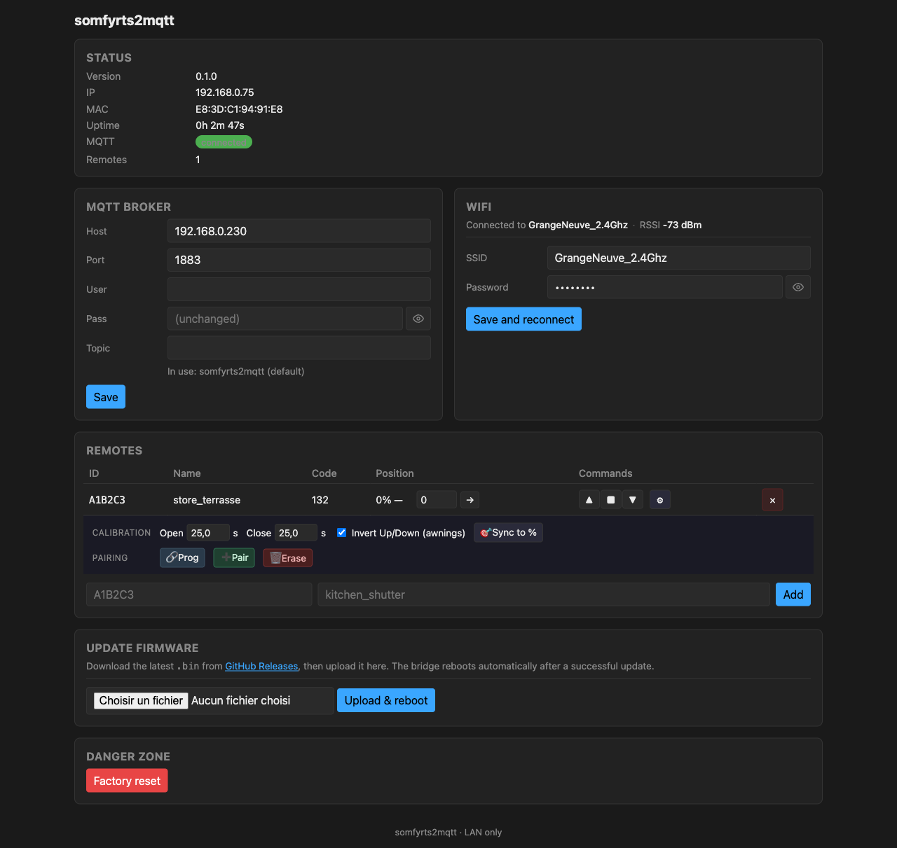
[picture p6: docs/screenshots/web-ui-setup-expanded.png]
Setup row expanded


The expanded sub-row exposes :

- **Device** (iter 022)
  - `Type` — dropdown. **Shutter** (default) or **Gate (portail)**. A **Gate**
    drops the time-based position (it is blind — the state cell reads "—") and
    its command cell shows **Open / Stop / Close** plus a **🔄 Toggle** button.
    Toggle emits the dedicated Somfy RTS **Toggle command `0x0C`** — the
    single-button cycle (open → stop → close → stop) that a sequential gate
    motor responds to. The calibration controls (durations, invert, `Sync to %`)
    are hidden. On MQTT it advertises `"Type":"gate"` and adds a `Toggle` verb
    (see [mqtt-api.md](mqtt-api.md)). Existing remotes stay Shutter; no re-pairing.
- **Calibration** (shutters only)
  - `Open <seconds>` — how long a full Up motion takes. Used by the position estimator.
  - `Close <seconds>` — same for Down. If left at 0, falls back to Open duration.
  - `Invert Up/Down` — checkbox. Tick this for a "store banne" or any motor whose Up button retracts (Up-perceived-as-close). The bridge swaps Up ↔ Down at the RF layer ; Position stays in user space (100 = visually open / extended). Composes with any type.
  - `Sync to %` — small target button. Click, enter a percentage, the bridge persists this value as the current Position **without emitting RF**. Useful after a manual operation (physical remote, power outage) to resync.

- **Pairing**
  - **🔗 Prog** — short PROG button. Used to acknowledge a pairing started by the motor (P2 button or a long press on an existing remote).
  - **➕ Pair** — emits a 3 s PROG press, the Somfy long-press for "enter pair mode".
  - **🗑 Erase** — emits a 7 s PROG press, the Somfy long-press for "delete a remote". The actual erase requires a follow-up brief Prog **from a different paired remote** (Somfy forbids self-erase by design). The UI prompts a confirmation dialog with the source / target workflow when you click Erase.

### Add a new remote

The form below the table is `<id_hex> <name>` + `Add` button. ID is 6 hex chars (00 0001 to FF FFFF), name matches `[a-zA-Z0-9_-]{1,32}`.

### Delete a remote

Click the red `×` cell at the end of the row. Confirmation dialog.

## Update firmware

OTA firmware upload section. Sits between Remotes and Danger zone.

Workflow :

1. Status line points to the [GitHub Releases page](https://github.com/mchacher/somfyrts2mqtt/releases/latest) where the official binaries live (one per supported board, plus a `sha256sums.txt`).
2. **File picker** — pick the `.bin` matching your board. The browser limits the input to `.bin` files via the `accept` attribute.
3. **Upload & reboot** button — submits the file as a multipart POST to `/api/firmware/upload`.
4. Two `confirm()` dialogs : the first shows the filename + size in KB ; the second warns that a bad binary can brick the device. Click OK on both to start.
5. The `<progress>` bar fills as chunks are streamed into the OTA partition.
6. On success : the bridge returns `200 {"ok":true,"rebooting":true}`, then `delay(500) + ESP.restart()` so the response actually flushes. The UI shows "Upload OK, rebooting…" and auto-reloads after 8 s.
7. On failure : the bridge returns `400 {"error":"<message>"}` (truncated binary, wrong magic byte, MD5 mismatch, partition full, …). The bridge keeps running the previous firmware ; the UI displays the error and re-enables the button.

Wrong-board guard : the very first chunk is inspected for the ESP image `chip_id` (offset 12). A binary built for another chip — e.g. a C3 `.bin` uploaded to an S3 board — is rejected immediately with `400 {"error":"firmware targets ESP32-C3, this bridge is ESP32-S3"}`, **before** `Update.begin()`, so no flash write ever happens. This turns the otherwise-silent "wrong file → bootloader rollback after reboot" into an explicit, actionable error. The guard lives in `include/ota_guard.h`.

Safety net : the dual-app partition table (`min_spiffs.csv`, two `app0` / `app1` slots of ~1.9 MB each) means the boot partition only flips after `Update.end()` confirms the new binary is valid. A botched upload cannot brick the device. A *valid* binary that crashes on boot is still a risk -- test in a dev env before tagging a Release.

## Danger zone

Single button : **Factory reset**. Two confirmation dialogs (because we mean it), then NVS is wiped and the bridge reboots straight into AP commissioning mode.

Use cases :
- Move the bridge to a new home / WiFi entirely
- Recover from a stuck state (rare)
- Reset before handing the device over

## Keyboard / mouse hints

- **Show / hide password** eye buttons next to every password field — Bonjour for users on shared screens.
- **Open / Close duration inputs** commit on blur (no separate Save button per row).
- **Position input + → button** issues `Position N` cmnd ; **🎯 Sync** updates the stored value without RF.
- **The page auto-refreshes** every 1 s while a shutter is moving — Position climbs / falls in real time. At rest, no polling.

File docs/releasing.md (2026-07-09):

# Releasing (maintainer)

How a new firmware version reaches end users. Most of it is automated ; the maintainer only tags + pushes.

## Versioning model

The displayed firmware version comes from `git describe --tags --dirty --always --match "v*"` at build time, evaluated by `scripts/release_version.py` :

| Git state | `FW_VERSION` |
|---|---|
| On a tagged commit (`v0.2.0`) | `0.2.0` (the leading `v` is stripped) |
| 3 commits past `v0.2.0` | `0.2.0-3-gabcd123` |
| Same as above, with uncommitted changes | `0.2.0-3-gabcd123-dirty` |
| No tag in history | `gabcd123` (short SHA fallback) |
| Git unavailable | `0.0.0-unknown` |

The Status card in the admin UI reads this string straight from the binary, so the displayed version always matches the running firmware.

There is **no `FW_VERSION` constant to bump manually** in `platformio.ini` -- the script handles it. The single source of truth is the git tag.

## Cut a release

The repo follows semver-ish (`vMAJOR.MINOR.PATCH`).

```bash
# 1. Make sure main is clean and CI is green
git checkout main
git pull

# 2. Tag the release (annotated, so it shows up in `git describe`)
git tag -a v0.2.0 -m "v0.2.0 - <short tagline>"

# 3. Push the tag (the workflow listens to push events on refs/tags/v*)
git push origin v0.2.0
```

Within ~2 minutes :
- `.github/workflows/release.yml` runs
- Builds `firmware.bin` for **both** envs (`esp32-c3-mini` and `esp32-s3-picybi`)
- Renames each to `somfyrts2mqtt-0.2.0-<env>.bin`
- Computes the SHA256 sums
- Creates a GitHub Release at `/releases/tag/v0.2.0`
- Attaches both `.bin` files and the `sha256sums.txt`
- Auto-generates a release body from PR titles + linked issues since the previous tag, categorised per `.github/release.yml` (Features / Fixes / Documentation / etc.)

End users go to <https://github.com/mchacher/somfyrts2mqtt/releases/latest>, download **the binary matching their board** (C3 vs S3 — the two are not interchangeable) and upload it via the bridge's web UI → Update firmware. The WebOTA handler rejects a binary built for the wrong chip, so a mismatch fails safely instead of bricking. No source-code checkout or PlatformIO needed on their side.

## Categorised release notes (PR labels)

The auto-generated body uses PR labels for grouping. Configure each PR (or label retroactively before tagging) with one of :

| Label | Group |
|---|---|
| `feature`, `enhancement`, `feat` | 🚀 Features |
| `fix`, `bug` | 🐛 Fixes |
| `docs`, `documentation` | 📚 Documentation |
| `ci`, `build` | 🔧 CI / build |
| `refactor`, `chore` | ♻️ Refactor / chore |
| `test`, `tests` | 🧪 Tests |
| Anything else | Other changes |

PRs with the `skip-changelog` or `dependencies` label are excluded entirely (dependabot noise stays out of the release body).

The mapping lives in `.github/release.yml`. Add new labels there if you adopt new conventions.

## Pre-releases

For a release candidate or a beta, use the standard `-rcN` / `-betaN` suffix in the tag :

```bash
git tag -a v0.2.0-rc1 -m "v0.2.0 release candidate 1"
git push origin v0.2.0-rc1
```

GitHub automatically flags `*-rc*`, `*-beta*`, `*-alpha*` tags as **pre-releases** ; they do NOT appear at `/releases/latest`. End users only get them if they navigate to the full release list.

The binaries are still built and attached -- pre-releases are a perfectly fine OTA target for early testers.

## Recover from a botched release

The release workflow does **not** push back to `main` -- nothing is modified after the build except the GitHub Release page. To withdraw a release :

```bash
# Delete the GitHub release (web UI : releases > pick > Delete release)
gh release delete v0.2.0 --repo mchacher/somfyrts2mqtt --yes

# Delete the tag locally and on remote
git tag -d v0.2.0
git push origin :refs/tags/v0.2.0

# Fix whatever was wrong, then tag again with a bumped patch number (v0.2.1)
```

Re-using the same tag number after deletion is technically possible but confusing for users who already downloaded the .bin -- bump to the next patch instead.

## Hotfix workflow

For a critical fix that needs to ship without the next batch of features :

1. Cut a `fix/...` branch off main, fix, PR, label `fix`, merge.
2. Tag the merge commit as `v0.2.1`, push.
3. Existing OTA mechanism rolls the fix out to anyone who clicks Upload in the admin UI.

Auto-update from a release feed (poll + notify) is not implemented yet. End users still pull updates manually -- low friction since the admin UI link goes straight to `/releases/latest`.

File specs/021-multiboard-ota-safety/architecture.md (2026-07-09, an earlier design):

# Architecture 021 — Multi-board build + OTA safety

## Touched modules

| File | Change |
| --- | --- |
| `include/config.h` | Add S3 CC1101 pinout block; broaden the `#error`; `FW_VARIANT` fallback define. |
| `platformio.ini` | Add `[env:esp32-s3-picybi]`. |
| `scripts/release_version.py` | Inject `-DFW_VARIANT="<env>"` from `env["PIOENV"]` (alongside `FW_VERSION`). |
| `include/ota_guard.h` | **New.** Pure header: `header_chip_id()` + `EXPECTED_CHIP_ID` + `chip_name()`. |
| `src/web_ui.cpp` | First-chunk chip guard in the OTA upload handler; `FW_VARIANT` in the Status card. |
| `src/main.cpp` | Temp CDC wait → `#if defined(WAIT_FOR_SERIAL)` guard (default off). |
| `.github/workflows/ci.yml` | Build + cppcheck both envs (matrix). |
| `.github/workflows/release.yml` | Build both envs; stage + publish both `.bin`; adjust release-notes body. |
| `test/test_ota_header/` | **New.** Native unit tests for `ota_guard`. |
| `docs/*`, `README.md`, `CLAUDE.md`| Re-introduce the two-board framing + S3 pinout + pick-your-binary notes. |

## Decisions

**Guard on `chip_id`, parsed from the image header, at the first OTA chunk.**
The `esp_image_header` sits at offset 0 of every ESP app image: byte 0 is the
magic `0xE9`, and `chip_id` (uint16, little-endian) is at offset 12
(`ESP_CHIP_ID_ESP32C3 = 5`, `ESP_CHIP_ID_ESP32S3 = 9`). The first WebOTA chunk
is far larger than 14 bytes, so we can validate before calling `Update.begin()`
/ `Update.write()` and fail fast with a precise message. *Rejected: relying on
the bootloader's post-reboot `chip_id` check alone* — it prevents a brick but
surfaces to the user as an unexplained rollback to the old version.

**`ota_guard` is a pure header, no `Update.h` / Arduino dependency.** Keeps the
parsing unit-testable from the `native` env (same pattern as
`include/shutter_state.h`). `web_ui.cpp` supplies the compile-time expected id
and calls the pure comparison; the header itself never touches hardware.

**`FW_VARIANT` = the env name, injected by the pre-script** (`env["PIOENV"]`
in `scripts/release_version.py`), mirroring how `FW_VERSION` is injected — not
via `${PIOENV}` interpolation in `platformio.ini`, which is not reliable for
the env name. The env name is the same token that disambiguates the release
filename, so what the user sees in the Status card matches the file they
downloaded. A `#ifndef FW_VARIANT` fallback in `config.h` keeps any build
without the pre-script compiling.

**CDC boot-wait becomes opt-in (`-DWAIT_FOR_SERIAL`), not shipped on.** A fixed
multi-second wait on every boot would slow power-loss recovery for a
"set-and-forget" bridge. Native-USB boards (C3/S3) lose the first serial lines
to USB re-enumeration; a developer who needs them builds with the flag. Default
production boot is unchanged.

**`chip_id` guard does not cover same-chip / different-pinout variants.**
Explicitly out of scope; a `FW_VARIANT` string check against the incoming
`esp_app_desc` is the documented follow-up if a second same-chip board appears.

## Expected chip id (compile-time)

```
CONFIG_IDF_TARGET_ESP32C3 → EXPECTED_CHIP_ID = 0x0005  ("ESP32-C3")
CONFIG_IDF_TARGET_ESP32S3 → EXPECTED_CHIP_ID = 0x0009  ("ESP32-S3")
```

## Flow (WebOTA upload)

```
POST /api/firmware/upload  (multipart, streamed)
  chunk index==0:
      len >= 14 && data[0]==0xE9 ?           no  → 400 "not an ESP image"
      cid = data[12] | data[13]<<8
      cid == EXPECTED_CHIP_ID ?               no  → 400 "firmware targets <X>, this bridge is <Y>"
      Update.begin(UPDATE_SIZE_UNKNOWN)
  chunk index>0: Update.write(chunk)
  final:          Update.end(true)  // MD5 verified, boot partition flipped
  complete:       200 {ok,rebooting} → delay(500) → ESP.restart()
```

No partition-table change (`min_spiffs.csv` already has `app0`/`app1`/`otadata`).

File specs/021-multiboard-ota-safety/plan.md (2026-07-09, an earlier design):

# Plan 021 — Multi-board build + OTA safety

## Steps

1. **Branch** `feat/esp32-s3-multiboard-ota` from `main`.
2. **`include/config.h`** — keep the S3 pinout block already staged; confirm the
   `#error` fallback lists both targets.
3. **`platformio.ini`** — keep `[env:esp32-s3-picybi]`; add
   `-DFW_VARIANT=\"${PIOENV}\"` to `[firmware_base].build_flags`.
4. **`include/ota_guard.h`** — new pure header:
   - `constexpr uint16_t EXPECTED_CHIP_ID` from `CONFIG_IDF_TARGET_*`.
   - `const char* chip_name(uint16_t id)` → "ESP32-C3" / "ESP32-S3" / "another chip".
   - `int32_t header_chip_id(const uint8_t* buf, size_t len)` — returns
     `CHIP_ID_INVALID` (-1) on `len < 14` or `buf[0] != 0xE9`, else the LE
     uint16 at offset 12. Sentinel return (not `std::optional`) so the header
     compiles under the arduino env's C++ standard, which is not guaranteed to
     be C++17. Doxygen per house style.
5. **`src/web_ui.cpp`**:
   - In `handle_firmware_upload`, at `index == 0`, run the guard before
     `Update.begin`. On mismatch, stash an error + short-circuit; the completion
     handler returns 400 with the message. Reuse the existing failure JSON path.
   - Status card: add a `FW_VARIANT` line/span next to the version.
6. **`src/main.cpp`** — wrap the CDC boot-wait in `#if defined(WAIT_FOR_SERIAL)`;
   default build has just `Serial.begin(115200); delay(200);` as before.
7. **`test/test_ota_header/`** — native Unity test: valid C3 header (cid 5),
   valid S3 header (cid 9), bad magic → nullopt, len 13 → nullopt, exact-14 buffer.
8. **`.github/workflows/ci.yml`** — matrix `env: [esp32-c3-mini, esp32-s3-picybi]`
   for build + cppcheck; keep the native `test` job.
9. **`.github/workflows/release.yml`** — build both envs; loop the stage/copy
   over both; keep the 0xE9 sanity + sha256; update the notes body.
10. **Docs** — `docs/hardware.md` (S3 pinout table), `docs/releasing.md` (two
    artifacts), `README.md` (two boards + pick-your-binary), `CLAUDE.md`
    (hardware section: add S3, drop "only C3").
11. **Build / check / test**:
    - `pio run -e esp32-c3-mini` and `pio run -e esp32-s3-picybi` clean.
    - `pio check -e esp32-c3-mini` / `-e esp32-s3-picybi` clean.
    - `pio test -e native` green (incl. `test_ota_header`).
12. **Flash + HW test** on the S3 (test plan below).
13. **PR** on `mchacher/somfyrts2mqtt`; link this spec; HW checklist in the body.

## Test plan (HW — ESP32-S3 PICYBI)

- **Nominal update**: build `esp32-s3-picybi`, upload its `firmware.bin` via the
  admin UI → progress reaches 100 %, board reboots, Status card shows
  `esp32-s3-picybi <version>`. Shutters still controllable afterwards.
- **Wrong-chip rejection**: upload an `esp32-c3-mini` `firmware.bin` via WebOTA
  → UI shows an error like "firmware targets ESP32-C3, this bridge is ESP32-S3",
  HTTP 400, **no reboot**, current firmware keeps running (verify a command
  still works). Expected serial (with `-DWAIT_FOR_SERIAL`): `[ota] reject: chip mismatch ...`.
- **Corrupt image** (regression of spec 016): truncate the correct S3 bin to
  half → `Update.end` fails MD5 → 400, no reboot.

## Edge cases
- [ ] First chunk smaller than 14 bytes (pathological client) → guard returns
      nullopt → treat as "not an ESP image", 400, no write.
- [ ] `pio run -e esp32-wroom` still fails "Unknown environment" (we did not
      resurrect WROOM — only added S3).
- [ ] C3 build unchanged: `FW_VARIANT` string present but no behaviour change;
      no CDC wait by default.
- [ ] CI YAML valid after matrix change (`gh workflow view`).

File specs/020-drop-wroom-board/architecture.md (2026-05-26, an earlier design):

# Architecture 020 — Drop ESP32 WROOM board

## Touched modules

| File | Change |
| --- | --- |
| `platformio.ini` | Delete `[env:esp32-wroom]` block. |
| `.github/workflows/ci.yml` | Remove `esp32-wroom` from the build matrix. |
| `.github/workflows/release.yml` | Drop the WROOM build step + the `firmware.bin` copy line for `esp32-wroom`. |
| `include/config.h` | Delete the WROOM CC1101 pinout block; keep C3 + the cppcheck-safe `#error` guard. |
| `src/wifi_manager.cpp` | Drop the stale "Harmless on WROOM" comment. |
| `README.md` | Remove WROOM mentions in supported boards / install snippets. |
| `CLAUDE.md` | Remove WROOM in HW context and pinout reminders. |
| `docs/hardware.md` | Remove the WROOM pinout / wiring tables. |
| `docs/releasing.md` | Remove the WROOM bin from the artifact list. |
| `docs/troubleshooting.md` | Remove the WROOM-specific entry. |
| `docs/setup.md` | Remove the "pick your board" sentence and any WROOM-specific install step. |

## Decisions

**Selected: hard removal across active code paths and live docs; historical
specs stay untouched.**

Specs 006/008/009/010/011/014/015/016/018 mention WROOM in passing
because they were the operating state at the time. Rewriting them would
be revisionist and offers no benefit — readers should still see what
the project supported in earlier iterations. New specs (this one and
onwards) reflect the C3-only world.

**Rejected: keeping the WROOM env behind a `keep_wroom = no` flag.**
Adds a second code path to maintain forever with zero users. If WROOM
support is ever needed again, it can be reintroduced in a future iter
based on the spec 008 multi-board history.

## Library + build impact

- `platformio.ini` loses one env. Default env stays `esp32-c3-mini`.
- CI build matrix goes from `[esp32-c3-mini, esp32-wroom]` to a single
  entry — roughly halves the CI build wall-time of the workflow.
- Release artifact set goes from two `.bin` files to one. The release
  notes already use the `vX.Y.Z` tag, no per-artifact name change.

## Flow

```
git checkout -b chore/drop-wroom-board
edit files (above)
pio run -e esp32-c3-mini   # must stay clean
pio check                  # must stay clean
pio test -e native         # 74 / 74
git commit -am ...
gh pr create
```

No runtime behaviour change — the C3 firmware is byte-for-byte
equivalent before/after this change (only the build matrix and the
unused WROOM pinout disappear).

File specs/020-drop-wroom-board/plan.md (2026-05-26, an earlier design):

# Plan 020 — Drop ESP32 WROOM board

## Steps

1. **Branch** `chore/drop-wroom-board` from `main`.
2. **`platformio.ini`** — remove the `[env:esp32-wroom]` block + the
   trailing comment above it. Keep `default_envs = esp32-c3-mini`.
3. **`.github/workflows/ci.yml`** — strip `esp32-wroom` from the build
   matrix `env: [...]` line.
4. **`.github/workflows/release.yml`** — drop the WROOM build step + the
   `cp .pio/build/esp32-wroom/firmware.bin ...` artifact copy.
5. **`include/config.h`** — remove the
   `#elif defined(CONFIG_IDF_TARGET_ESP32)` block (the WROOM pinout).
   Update the `#error` fallback message to reference C3 only.
6. **`src/wifi_manager.cpp`** — drop the "Harmless on WROOM" inline
   comment.
7. **`README.md`** — remove WROOM mentions in supported-hardware /
   install snippets. Keep the C3 Super Mini narrative.
8. **`CLAUDE.md`** — remove WROOM in the HW context and pinout
   reminders sections.
9. **`docs/hardware.md`** — remove the WROOM pinout table + any
   "alternative board" framing.
10. **`docs/releasing.md`** — remove the WROOM bin from the listed
    artifacts.
11. **`docs/troubleshooting.md`** — remove the WROOM-specific entry.
12. **`docs/setup.md`** — remove the WROOM step.
13. **Build / static check / native tests**:
    - `~/.platformio/penv/bin/pio run -d . -e esp32-c3-mini` clean.
    - `~/.platformio/penv/bin/pio check -d .` clean.
    - `~/.platformio/penv/bin/pio test -d . -e native` 74 / 74.
14. **Final grep** to confirm no leftover WROOM references in active
    paths:
    `grep -ri "wroom" src/ include/ .github/ docs/ README.md CLAUDE.md`
    should return empty.
15. **PR** on `mchacher/somfyrts2mqtt`.

## Test plan (HW)

No hardware test required — this is a pure scope reduction with no
runtime impact on the supported C3 board. Sanity check on the bench
after merge:

- [ ] Existing C3 firmware OTA'd from a v0.3.x release continues to
      boot, associate WiFi, connect MQTT.
- [ ] The next release after this PR ships a single
      `somfyrts2mqtt-<v>-esp32-c3-mini.bin` artifact and the GitHub
      release body no longer lists a WROOM bin.

## Edge cases

- [ ] CI workflow YAML stays syntactically valid after the matrix
      reduction (`gh workflow view` is happy).
- [ ] `pio run -e esp32-wroom` fails with the explicit
      "Unknown environment" error — confirms removal.
- [ ] `tools/` scripts (if any are board-aware) keep working — verify
      `pio device list` based scripts don't try `esp32-wroom`.

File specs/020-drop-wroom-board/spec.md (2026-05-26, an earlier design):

# 020 — Drop ESP32 WROOM board

## Goal
Drop the dormant `esp32-wroom` build target and every reference to it across
the codebase. The C3 Super Mini is the only board ever shipped in
practice; carrying the WROOM env adds CI build time, doubles release
artifacts, and dilutes the documentation with a variant that is no longer
maintained.

## Scope

In scope:
- `platformio.ini`: remove the `[env:esp32-wroom]` block. `esp32-c3-mini`
  stays as the only firmware env (plus `native` for tests).
- `.github/workflows/ci.yml`: drop `esp32-wroom` from the build matrix.
- `.github/workflows/release.yml`: drop the WROOM build step + the
  matching `cp .pio/build/esp32-wroom/firmware.bin …` artifact line.
- `include/config.h`: remove the `#elif defined(CONFIG_IDF_TARGET_ESP32)`
  CC1101 pinout block (the WROOM pinout). Tidy the `#error` fallback so
  the only supported target is `CONFIG_IDF_TARGET_ESP32C3`.
- `src/wifi_manager.cpp`: drop the stale "Harmless on WROOM" comment
  next to the TX-power clamp.
- `README.md`, `CLAUDE.md`, `docs/hardware.md`, `docs/releasing.md`,
  `docs/troubleshooting.md`, `docs/setup.md`: remove WROOM mentions,
  pinout tables, and "two boards" framing. Keep the C3 Super Mini
  pinout / hardware notes intact.

Out of scope:
- The historical specs under `specs/006-...` through `specs/018-...`
  that mention WROOM — those are append-only project records and stay
  unchanged.
- Removing tooling from `tools/` (none of it is WROOM-specific).
- Any C3-side refactor — pinouts, TX power workaround, captive portal,
  etc. stay exactly as today.

## Acceptance criteria

- [ ] `grep -ri "wroom" src/ include/ .github/ docs/ README.md CLAUDE.md`
      returns zero matches (excluding tests / .pio / .git).
- [ ] `pio run -e esp32-c3-mini` clean, zero warnings.
- [ ] `pio check` clean.
- [ ] `pio test -e native` — 74 cases still pass.
- [ ] `pio run -e esp32-wroom` fails with "Unknown environment" (the env
      no longer exists in `platformio.ini`).
- [ ] CI workflow file is syntactically valid (`gh workflow view` is
      happy) and the matrix has a single entry for `esp32-c3-mini`.
- [ ] Release workflow no longer references the WROOM .bin filename.

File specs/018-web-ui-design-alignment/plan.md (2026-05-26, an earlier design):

# Plan 018 — Captive portal aligned on sowel-energy-display

## Steps

1. **Add `include/captive_portal.h`** with the `[[noreturn]] void run(const char* ap_ssid, uint32_t timeout_s)` declaration.

2. **Add `src/captive_portal.cpp`** with:
   - `STYLE[]` PROGMEM constant copied verbatim from
     `sowel-energy-display/src/portal.cpp`.
   - `html_escape()` helper (copy from energy-display).
   - `scan_networks()` that returns an `<option>` list sorted by RSSI desc.
   - `render_form(last_error)` rendering the SOWEL header + WiFi card.
   - `render_saved_page()` rendering the "Configuration enregistrée,
     redémarrage…" confirmation.
   - `on_save(req)` extracting `wifi_ssid` + `wifi_pass`, validating, calling
     `nvs_store::set_wifi_creds()`, flipping `pending_reboot`.
   - `run()` orchestrating AP setup + DNSServer + AsyncWebServer + the
     `while` loop with idle timeout + final `ESP.restart()`.

3. **Edit `src/wifi_manager.cpp`**:
   - Remove `#include <WiFiManager.h>`.
   - Replace the body of `start_ap()` with a single call to
     `captive_portal::run(ap_ssid, WIFI_AP_TIMEOUT_S)`.
   - Keep the `chip_suffix` -> `ap_ssid` formatting unchanged.

4. **Edit `platformio.ini`**: remove the `tzapu/WiFiManager` line from
   `lib_deps`. Confirm `me-no-dev/ESPAsyncWebServer` and `DNSServer` (core)
   are still listed where needed.

5. **Build**: `~/.platformio/penv/bin/pio run -d .`
   - Zero warnings, zero errors on both envs (`esp32-c3-mini`, `esp32-wroom`).

6. **Static check**: `~/.platformio/penv/bin/pio check -d .` — clean.

7. **Native tests**: `~/.platformio/penv/bin/pio test -d . -e native` —
   no captive-portal-specific tests (HW-bound), but the existing suites
   (NVS, parsers, etc.) must still pass.

8. **Flash to bench device**: `~/.platformio/penv/bin/pio run -d . -t upload`.

9. **Run HW test plan below.**

## Test plan (HW)

Prerequisite: wipe NVS on the bench device so the bridge boots into AP
mode. Either run a factory reset from the LAN page, or flash with `pio run
-t erase` + upload.

### Captive flow

- [ ] Serial log shows `[wifi] captive portal SSID=somfyrts2mqtt-XXXX
      timeout=300s` (or whatever `WIFI_AP_TIMEOUT_S` is set to).
- [ ] A 2.4 GHz network named `somfyrts2mqtt-XXXX` is visible from a phone.
- [ ] Joining the AP triggers the iOS "Sign in to Wi-Fi network" /
      Android "Sign in to network" captive-portal sheet automatically
      (DNS catch-all + standard probe responses).
- [ ] If the captive sheet doesn't auto-open, manually browsing to
      `http://192.168.4.1/` still loads the page (fallback).

### Visual

- [ ] Page background is the light Sowel `#F8F9FA` grey, NOT tzapu's
      generic dark grey.
- [ ] "SOWEL" brand displayed at top (letter-spacing 4px, color
      `#1A4F6E`), with tagline "Configuration du bridge Somfy RTS" below.
- [ ] WiFi card has a white background, rounded corners, Sowel-primary
      uppercase h2.
- [ ] SSID select shows the list of nearby networks sorted by signal
      strength.
- [ ] Password field has the eye-toggle button on the right; clicking
      it switches type=password ↔ type=text.
- [ ] Submit button is a full-width amber Sowel-primary button labelled
      "Valider et redémarrer".
- [ ] Page renders OK with no Google Fonts (system stack fallback —
      Apple system / Inter / Segoe UI / Roboto / sans-serif).

### Submit flow

- [ ] Submitting with a valid SSID + password:
      - returns a "Configuration enregistrée…" page,
      - serial log shows `[wifi] saved new creds ssid=<…>, rebooting into STA`,
      - device reboots within 1 s,
      - boots into STA, joins the saved network successfully.
- [ ] Submitting with an empty SSID: page re-renders with a red error
      banner "SSID requis" above the form (no NVS write, no reboot).
- [ ] Submitting an open network (empty password) is accepted and works.

### Timeout flow

- [ ] Leave the captive open without submitting for the full timeout.
      Serial logs `[wifi] captive portal timed out after Xs without
      save, rebooting`. Bridge reboots and re-enters AP mode if NVS
      is still empty.

### PA saturation regression check (C3 Super Mini)

- [ ] On a Super Mini board, the AP is joinable from a phone (no
      `WL_NO_SSID_AVAIL` or auth failures). TX power should be clamped
      to `WIFI_POWER_8_5dBm` while in AP mode.

### Build size sanity

- [ ] `pio run -e esp32-c3-mini` output shows a SMALLER firmware after
      dropping tzapu (typical delta -40 to -80 KB). Logged for the PR
      body.

## Edge cases

- [ ] Phone disconnects mid-submit → the user re-joins the AP, hits the
      page again, can re-submit. No stale state.
- [ ] Bridge has 0 visible networks during scan → friendly "Aucun réseau
      visible" message with a Re-scan link.
- [ ] User enters a 64-char password (boundary): `maxlength="63"`
      enforces, server-side also caps at 63 (the WPA2-PSK max).
- [ ] SSID contains characters that would break HTML (`<`, `>`, `&`,
      quotes) → all rendered through `html_escape()`.

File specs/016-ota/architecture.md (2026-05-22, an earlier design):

# Architecture 016

## Touched modules

| File | Change |
|---|---|
| `src/web_ui.cpp` | Add `/api/firmware/upload` POST handler (multipart streaming) + Update section in the embedded HTML / JS |
| `src/wifi_manager.cpp` | ArduinoOTA setup in `STA_GOT_IP` event handler ; `ArduinoOTA.handle()` in `wifi::loop()` |
| `include/config.h` | New `OTA_PASSWORD` compile-time string with a "change me" default |
| `.github/workflows/release.yml` | New workflow : on tag push, build firmware for both envs, attach .bin to a GitHub Release |
| `docs/setup.md`, `docs/web-ui.md` | "Update from a GitHub Release" section ; WebOTA walkthrough |
| `README.md` | Link to the Releases page in the Quickstart |

No new lib dependency (Update, ArduinoOTA both ship with Arduino-ESP32).

## WebOTA path

```
Browser                                    Bridge (admin UI)
   │                                            │
   ├── GET /                            ────────▶│ Render Update section + Status / MQTT / WiFi / Remotes
   │                                            │
   ├── user picks firmware.bin                  │
   ├── user confirms (2-step dialog)            │
   ├── POST /api/firmware/upload      ─────────▶│ AsyncWebServer onUpload callback :
   │   Content-Type: multipart/form-data        │   - first chunk : Update.begin(UPDATE_SIZE_UNKNOWN)
   │   <binary chunks>                          │   - each chunk  : Update.write(buf, len)
   │                                            │   - last chunk  : Update.end(true)
   │                                            │
   │◀────────── 200 {"ok":true,"rebooting":true}
   │                                            │
   │                                            ├── delay(500)  -- let HTTP flush
   │                                            └── ESP.restart()
   │
   │ (browser waits ~5 s, then polls /api/status until the new version appears)
```

`Update.end(true)` returns true only after :
- Wrote at least one chunk
- Embedded MD5 (Arduino-ESP32 appends one) matches the computed MD5
- The OTA slot fits the binary

On failure : the bridge keeps booting from the current partition. The OTA slot is left in an "invalid" state and the next attempt overwrites it.

## ArduinoOTA path

```cpp
// In wifi_manager.cpp, on STA_GOT_IP, alongside MDNS.begin :
ArduinoOTA.setHostname(WiFi.getHostname());          // "somfyrts2mqtt"
ArduinoOTA.setPassword(OTA_PASSWORD);                // from config.h
ArduinoOTA.onStart(...) / onProgress(...) / onEnd(...) / onError(...) ;
ArduinoOTA.begin();

// In wifi::loop() :
ArduinoOTA.handle();
```

PlatformIO discovers the bridge via mDNS (`_arduino._tcp` advertised by ArduinoOTA.begin()) and pushes firmware over a TCP / UDP combo. Auth via the password.

`platformio.ini` example for the dev :

```ini
[env:esp32-c3-mini-ota]
extends = env:esp32-c3-mini
upload_protocol = espota
upload_port     = somfyrts2mqtt.local
upload_flags    = --auth=${env:SOMFYRTS_OTA_PASSWORD}
```

## GitHub Releases workflow

`.github/workflows/release.yml` outline :

```yaml
on:
  push:
    tags: ['v*']
jobs:
  release:
    runs-on: ubuntu-latest
    steps:
      - uses: actions/checkout@v4
      - uses: actions/setup-python@v6
      - run: pip install platformio
      - run: pio run -e esp32-c3-mini -e esp32-wroom
      - name: Rename binaries
        run: |
          VERSION=${GITHUB_REF#refs/tags/v}
          mkdir -p release
          cp .pio/build/esp32-c3-mini/firmware.bin release/somfyrts2mqtt-${VERSION}-esp32-c3-mini.bin
          cp .pio/build/esp32-wroom/firmware.bin   release/somfyrts2mqtt-${VERSION}-esp32-wroom.bin
      - uses: softprops/action-gh-release@v2
        with:
          files: release/*.bin
          generate_release_notes: true
```

The Release body uses GitHub's auto-generated notes (PR titles / commits since the previous tag). A more curated CHANGELOG.md can replace this later.

## Update section in the admin UI

Sits in a new Card between `WiFi` and `Remotes` (or under `Danger zone` if we want to keep it less prominent). Markup :

```html
<section>
  <h2>Update</h2>
  <p class="kv">
    <span>Current version</span><span data-k="version_now">0.1.0</span>
    <span>Latest release</span>
       <a href="https://github.com/mchacher/somfyrts2mqtt/releases/latest" target="_blank">GitHub</a>
  </p>
  <form id="ota-form">
    <input type="file" name="firmware" accept=".bin" required/>
    <button class="primary" type="submit">Upload &amp; reboot</button>
  </form>
  <progress id="ota-progress" value="0" max="100" hidden></progress>
  
</section>
```

JS uses `XMLHttpRequest` (instead of `fetch`) because XHR exposes upload-progress events natively ; updates the `<progress>` bar. Two `confirm()` calls before sending (same Pattern as Factory reset).

## Partition layout sanity check

`min_spiffs.csv` (PlatformIO default for boards with 4 MB flash) :

| Name | Type | Subtype | Offset | Size |
|---|---|---|---|---|
| nvs | data | nvs | 0x9000 | 0x5000 (20 KB) |
| otadata | data | ota | 0xe000 | 0x2000 (8 KB) |
| app0 | app | ota_0 | 0x10000 | 0x1E0000 (1.875 MB) |
| app1 | app | ota_1 | 0x1F0000 | 0x1E0000 (1.875 MB) |
| spiffs | data | spiffs | 0x3D0000 | 0x30000 (192 KB) |

Verified : ample headroom (current firmware uses ~1.1 MB), 2 OTA slots active, otadata partition present. No `partitions.csv` change needed.

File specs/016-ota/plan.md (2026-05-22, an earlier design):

# Plan 016

## Steps

The work splits into 4 independent chunks. Each chunk is buildable and shippable on its own.

1. **ArduinoOTA wiring** — ~15 lines.
   - Add `OTA_PASSWORD` to `include/config.h` with a "change me locally" default + a `.gitignored` `secrets.h` override.
   - In `wifi_manager.cpp` STA_GOT_IP handler : `ArduinoOTA.setHostname(...)` + `setPassword(...)` + `begin()` + log on start / progress / end / error.
   - In `wifi::loop()` : `ArduinoOTA.handle()`.
   - Add `[env:esp32-c3-mini-ota]` to `platformio.ini` (extends the regular env with `upload_protocol = espota`).
   - HW test : flash via USB first (since the bridge is not yet OTA-capable), then `pio run -e esp32-c3-mini-ota -t upload --upload-flags "--auth=..."`. Bridge accepts the new firmware.

2. **WebOTA backend** — ~50 lines in `web_ui.cpp`.
   - `s_server.on("/api/firmware/upload", HTTP_POST, ...completion..., ...upload...)`.
   - The upload callback streams chunks straight to `Update.write()`. First chunk : `Update.begin(UPDATE_SIZE_UNKNOWN)` ; last chunk : `Update.end(true)`.
   - Completion handler sends `200 {"ok":true}` then `delay(500)` + `ESP.restart()`.
   - Failure paths : `Update.printError(Serial)` + 400 with the error message.
   - Two-step `confirm()` dialogs in the JS handler before the upload starts.

3. **WebOTA UI** — ~40 lines of HTML / JS in `web_ui.cpp`'s `INDEX_HTML`.
   - New `<section><h2>Update</h2>...</section>` between WiFi and Remotes.
   - File picker + submit ; XHR with progress events ; `<progress>` bar ; success / error message ; auto-poll `/api/status` after the upload to detect the reboot.
   - Link to the GitHub Releases page.

4. **GitHub Actions release workflow** — `.github/workflows/release.yml`.
   - Trigger : `push: tags: ['v*']`.
   - Steps : checkout, install PlatformIO, `pio run -e esp32-c3-mini -e esp32-wroom`, rename binaries to `somfyrts2mqtt-<version>-<env>.bin`, attach to a GitHub Release.
   - Auto-generate release notes from commit messages since previous tag.
   - Documentation update : README quickstart + `docs/setup.md` "Update from a GitHub Release" section + `docs/web-ui.md` Update card walkthrough.

## Test plan

### Native (Unity)
- No new pure-logic helpers. Skip native tests for this iter (lib calls all the way through).

### HW (browser + PlatformIO)

Preconditions : bridge running on the current firmware, accessible at `somfyrts2mqtt.local`.

| Case | Action | Expected |
|---|---|---|
| **WebOTA happy path** | Build a new firmware with a bumped `FW_VERSION` to e.g. `0.2.0`. Browse to the bridge → Update section → pick the new `.bin` → confirm twice → Upload | Progress bar fills, "Rebooting" message, page reload after ~5 s, Status card now shows `0.2.0` |
| **WebOTA truncated binary** | Pick a `.bin` truncated to half size | 400 `{"error":"MD5 mismatch"}`. Status card stays on the old version. No reboot |
| **WebOTA wrong file (PNG)** | Pick a non-binary file | 400 `{"error":"Magic byte is wrong, not 0xE9"}` (or similar). No partition switch |
| **ArduinoOTA dev push** | `pio run -e esp32-c3-mini-ota -t upload --upload-flags "--auth=<password>"` | New firmware flashed, bridge reboots |
| **ArduinoOTA wrong password** | Same with a bogus `--auth=...` | PlatformIO reports `Authentication Failed`. Bridge keeps running |
| **GitHub Release workflow** | `git tag v0.2.0 && git push origin v0.2.0` | Actions run picks up the tag, builds both envs, creates a Release with `somfyrts2mqtt-0.2.0-esp32-c3-mini.bin` + `somfyrts2mqtt-0.2.0-esp32-wroom.bin`. Visible at `/releases/latest` |
| **End-to-end (user perspective)** | From a fresh laptop : go to `/releases/latest` → download the C3 binary → open `http://somfyrts2mqtt.local/` → Update → upload → bridge restarts on the new version | No USB cable was plugged in. The update completed entirely over WiFi |

## Risks

- **Bricking via a bad upload.** The dual-app partition layout protects against truncated / corrupted binaries — the bridge keeps booting from the previous partition until `Update.end()` succeeds. But a *valid* binary that crashes on boot would still brick. Mitigation : test the binary locally (USB) before tagging a release, or use a "test in dev env first" rule. ESP32 has a `rollback_app` feature (boots back to the previous slot after N failed restarts) that we can opt into in a follow-up iter if needed.
- **OTA security.** WebOTA inherits the LAN-only attack model of the rest of the admin UI ; same threat profile. ArduinoOTA requires a password. Both rely on the user trusting their LAN. Not adding code signing for now ; would be a separate iter.
- **`firmware.bin` size growing past 1.875 MB.** Current size is ~1.1 MB so plenty of headroom, but worth tracking. CI can grep `Flash:` from `pio run` output and fail if past a threshold ; defer to a future iter.
- **Tag ↔ FW_VERSION drift.** Easy to tag `v0.2.0` while the source still says `0.1.0`. A `scripts/release.sh` that bumps `FW_VERSION` + commits + tags atomically is a useful follow-up.

## Order of work + commits

Suggested commits (kept small, reviewable independently) :

1. `feat(ota): ArduinoOTA dev workflow + mDNS service`
2. `feat(ota): WebOTA upload endpoint`
3. `feat(ui): firmware upload section with progress bar`
4. `ci: build + publish firmware binaries on tag push`
5. `docs: WebOTA + GitHub Releases instructions in setup.md, web-ui.md, README`

Each commit builds clean, builds on both envs, native tests untouched.

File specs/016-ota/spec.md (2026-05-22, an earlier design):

# 016 — OTA firmware update (WebOTA + ArduinoOTA)

## Goal
Let the user update the bridge firmware over WiFi, without ever plugging in USB again after the initial commissioning. Two complementary paths :

- **WebOTA** — drag-and-drop a `firmware.bin` from the admin UI. End-user friendly, no extra tooling.
- **ArduinoOTA** — `pio run -t upload --upload-port somfyrts2mqtt.local` from PlatformIO. Developer workflow, ~10 lines of code in addition.
- **GitHub Releases** — every tagged version (`v0.2.0`, `v0.2.1`, …) ships a downloadable `firmware.bin` per board, attached to the release page. Users grab the binary from <https://github.com/mchacher/somfyrts2mqtt/releases>, upload it via WebOTA. Built by CI on tag push.

## Background
Today the only update path is USB + `pio run -t upload`. Once the bridge is wired in place behind a shutter or in a junction box, that becomes painful. ESP32 supports OTA natively via the dual-app partition scheme and the `Update` library ; we already use the `min_spiffs.csv` partition table which ships two ~1.9 MB OTA slots (`app0` / `app1`), so A/B rollback is gratuitous : the chip boots from the partition that successfully completed `Update.end()` ; on a failed write the previous one stays active.

## Scope

**In scope:**

### WebOTA
- New section in the admin UI : **Update** (placed in the Danger zone area, next to Factory reset).
- File input + Upload button + progress bar. Accepts `.bin` only ; max size = the free OTA slot (~1.9 MB).
- `POST /api/firmware/upload` multipart handler in `web_ui.cpp` using the `AsyncCallbackJsonWebHandler`-equivalent for binary uploads (`s_server.on(..., HTTP_POST, ..., onUpload)`).
- Backend uses `Update.begin(UPDATE_SIZE_UNKNOWN)` → `Update.write(buf, len)` chunks → `Update.end(true)`. The lib validates the embedded MD5 and rejects truncated / corrupted binaries.
- On success : log, return 200 with `{"ok":true,"rebooting":true}`, defer a 500 ms `delay()` and `ESP.restart()` so the response actually flushes.
- On failure : 400 with `{"error":"<Update.errorString()>"}`. No partition switch happens ; the current firmware keeps running.
- Two-step confirm dialog in the UI (same pattern as Factory reset).
- Visible firmware version in the Status card (already there since iter 001), so the user can verify the new version after reboot.

### ArduinoOTA (dev workflow bonus)
- Enable in `wifi_manager.cpp` once `STA_GOT_IP` fires (alongside mDNS).
- `ArduinoOTA.setHostname(WiFi.getHostname())` so PlatformIO sees `somfyrts2mqtt.local`.
- `ArduinoOTA.setPassword(OTA_PASSWORD)` — compile-time string from `config.h`, default value clearly marked "change me", short doc note.
- `ArduinoOTA.begin()` + `ArduinoOTA.handle()` in `loop()`.
- mDNS service advertise `_arduino._tcp` on port 3232 (the default ArduinoOTA port) so PlatformIO discovers the bridge automatically.

### GitHub Releases publishing
- New CI job in `.github/workflows/release.yml` (or extend the existing one) triggered on `push: tags: ['v*']`.
- Steps : checkout, set up PlatformIO, `pio run -e esp32-c3-mini` + `pio run -e esp32-wroom`, take the resulting `.pio/build/<env>/firmware.bin`, rename to `somfyrts2mqtt-<version>-<env>.bin`, create a GitHub Release with both binaries attached and an auto-generated body (commit messages since the previous tag or a manual `CHANGELOG.md` block).
- Versioning : the `FW_VERSION` macro in the firmware (currently `0.1.0`) should match the git tag. A small `scripts/release.sh` could bump both atomically ; for now manual bump + tag is fine.
- Releases are marked "latest" automatically by GitHub. Pre-releases (`v0.2.0-rc1`) flagged as such via the tag name.

**Out of scope:**
- HTTPS / code-signed updates. The bridge is LAN-only ; any peer on the LAN that hits the admin UI can already operate the shutters. Adding signature verification is a separate hardening iter if ever needed.
- Auto-update from a remote URL / GitHub Releases poll. Single-bridge users do not need fleet management. Can be added in a future iter for multi-bridge / kiosk deployments.
- SPIFFS / LittleFS data partition updates. The firmware does not store user data in a filesystem partition (all in NVS) ; no need to push a `littlefs.bin`.
- Rollback button in the UI. The dual-app A/B partition scheme already handles failed updates ; an explicit "go back to the previous firmware" requires user-space tracking that we do not need yet.
- OTA from MQTT (`cmnd/.../Update` with a URL). Out of scope ; can be added if Sowel wants centralised updates.

## Acceptance criteria
- [ ] Build clean on `esp32-c3-mini` and `esp32-wroom`. `pio check` zero defects, `pio test -e native` all green.
- [ ] HW : take a `firmware.bin` produced by `pio run`, upload it via the admin UI's Update section. Progress bar reaches 100 %, bridge reboots, Status card shows the new version.
- [ ] HW : intentionally truncate the binary to half its size, upload → backend rejects with 400 `{"error":"MD5 mismatch"}` (or equivalent), bridge keeps running the old firmware (no reboot).
- [ ] HW : `pio run -t upload --upload-port somfyrts2mqtt.local --upload-flags "--auth=<password>"` succeeds. Bridge reboots into the new firmware.
- [ ] HW : wrong ArduinoOTA password → upload rejected, bridge keeps running.
- [ ] CI : push a `v0.2.0` tag → release workflow runs → release page lists `somfyrts2mqtt-0.2.0-esp32-c3-mini.bin` and `somfyrts2mqtt-0.2.0-esp32-wroom.bin` as downloadable assets.
- [ ] Documentation : `docs/setup.md` and `docs/web-ui.md` gain a "Update from a GitHub Release" section. README quickstart links to the Releases page as the user-facing source of binaries.
- [ ] CI green on the PR.

## Decisions
- **Update via existing AsyncWebServer.** Not a new HTTPServer instance. Keeps the firmware compact and matches the rest of the admin UI.
- **No JSON body, multipart upload.** AsyncWebServer's `onUpload` callback streams chunks straight to `Update.write()` — never holds the full binary in RAM.
- **No size pre-flight.** `Update.begin(UPDATE_SIZE_UNKNOWN)` accepts any size up to the partition limit ; the IDF will fail the `end()` if the slot is overflowed. Keeps the UI / backend contract simple.
- **Two-step confirm in the UI**, same pattern as Factory reset. OTA bricks the device on a botched binary ; a single misclick must not trigger it.
- **Dev OTA password in `config.h`** with a clearly marked default. Treated like the legacy WIFI_PASSWORD default : developers can set their own locally, no friction for the captive-portal-commissioned path (ArduinoOTA is dev-only ; production users should not need it).
- **mDNS advertises both services.** `_http._tcp` (iter 015) + `_arduino._tcp` (this iter). PlatformIO + browsers discover the bridge under one mDNS name.
- **No partition table change.** `min_spiffs.csv` already has `app0` + `app1` + `otadata`. Verified.
- **Releases shipped via GitHub Actions, not from a developer's laptop.** Reproducible builds, no "works on my machine", and the CI matrix already runs on every PR -- adding a release-on-tag job is mostly YAML.
- **No code-signing of release binaries** for now. Same rationale as the WebOTA upload : LAN-only attack surface. A future iter can add SHA256 sums + checksum verification in the WebOTA UI if needed.

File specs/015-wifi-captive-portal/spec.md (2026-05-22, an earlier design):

# 015 — WiFi captive portal (Tasmota-style commissioning)

## Goal
Remove the need to flash WiFi credentials at compile time. A fresh box boots into a SoftAP captive portal that lets the user enter SSID + password from any phone or laptop. A box already on a network can be reconfigured from the admin UI without ever going back to AP mode. If the box is physically inaccessible (admin UI unreachable, hidden behind a shutter), 4 rapid power-cycles force AP recovery — no serial console, no factory reset, no firmware re-flash.

## Background
Today `wifi_manager.cpp` calls `WiFi.begin(WIFI_SSID, WIFI_PASSWORD, ...)` with compile-time constants from `config.h`. Provisioning a new box requires editing those constants and re-flashing. `config.h:46` already names a placeholder AP SSID but no implementation exists. NVS has `wifi.ssid` / `wifi.bssid` / `wifi.channel` (used today only for the BSSID fast-reconnect hint) but no `wifi.pass`.

This iter aligns with Tasmota's actual `WifiConfig 4` (WIFI_RETRY) default behavior :
- AP mode only when there is no choice : either no creds in NVS, or the user explicitly forces recovery.
- If creds exist but the network is down, retry STA forever — the box reconnects automatically as soon as the router is back, no manual intervention needed.
- Recovery from a stale config (wrong creds, moved router, lost admin UI access) is via **4 rapid power-cycles** : a tiny boot counter in NVS that increments at every boot and resets after a few seconds of stable uptime. Reaching the threshold forces AP mode for one boot only. Power management hardware (a wall switch, a relay, the PSU socket) is enough — no GPIO button required.

For the common "I am changing my router and the box is still on the LAN" case, a WiFi form is added to the admin UI : same effect as the captive portal but reachable while STA is up.

## Scope

**In scope:**

### NVS additions
- `wifi.pass` : string, default `""`. Reuse the existing `wifi.ssid` (currently always empty in fresh installs ; no migration concern).
- `wifi.boot_count` : uint8, default 0. Incremented at every boot, reset to 0 after `WIFI_BOOT_STABLE_MS` of uptime (default 5000 ms).
- On AP-mode save, also clear `wifi.bssid` / `wifi.channel` to force a clean scan on the next boot.

### Boot decision tree (in `wifi_manager::init`)
1. Read `wifi.boot_count` ; increment ; save. Schedule a `wifi.boot_count = 0` write at `now + WIFI_BOOT_STABLE_MS`.
2. If `wifi.boot_count >= WIFI_BOOT_AP_THRESHOLD` (default 4) → enter AP mode. Reset the counter to 0 before starting AP (so a single power-cycle out of AP returns to STA).
3. Else if `wifi.ssid` is empty → enter AP mode.
4. Else `WiFi.begin(ssid, pass)` with the BSSID hint (existing fast-reconnect path). On disconnect, keep retrying STA forever (existing reconnect logic stays).

### AP mode
- SoftAP SSID `somfyrts2mqtt-<chipId6>` (chipId6 = last 6 hex of MAC, matches the MQTT `client_id` suffix). Open network — short-lived commissioning on local LAN, no password needed.
- IP `192.168.4.1`, DHCP for the connecting client.
- `DNSServer` resolves every query to `192.168.4.1` → triggers the OS captive-portal pop-up on iOS / Android / macOS / Win11.
- Captive portal HTML on the existing `AsyncWebServer` instance, with a separate route set registered only in AP mode :
  - `GET /` → page with a refreshable WiFi scan dropdown + password input + Save button.
  - `GET /scan.json` → `[{ssid, rssi, secure, channel}, ...]` from `WiFi.scanNetworks()`.
  - `POST /save` → body `{ssid, pass}`. Non-empty SSID required. Writes NVS, responds 204, then `ESP.restart()` after a 1 s defer to flush the response.
  - All other routes return 404 in AP mode. The admin UI (Status / MQTT / Remotes / Danger zone) is NOT served in AP mode.
- **AP timeout** : after `WIFI_AP_TIMEOUT_MS` (default 5 min) without a successful `POST /save`, `ESP.restart()`. Prevents the box from being stuck in AP forever if a recovery trigger fired by accident — the next boot tries STA with whatever creds are still in NVS.

### Admin UI WiFi form (STA mode only)
- New `<section><h2>WiFi</h2>...</section>` in `web_ui.cpp`, between "MQTT broker" and "Remotes".
- Fields : SSID (text), Password (password, placeholder `(unchanged)`). Current connected SSID + RSSI shown read-only above the form for context.
- Save → `POST /api/wifi` `{ssid, pass}`. Non-empty SSID required. Writes NVS, 204, deferred restart. Same NVS path as the captive portal `/save`.

### `config.h` cleanup
- `WIFI_SSID` / `WIFI_PASSWORD` stay as compile-time constants but **default to `""`**. A fresh checkout boots into AP mode immediately. If a developer wants to skip the AP dance during local testing, they can still set the constants in their local `config.h` — the firmware uses them as the first-boot defaults and writes them to NVS on the first successful STA association.

### Late additions (post-step-4)
- **mDNS responder** : `MDNS.begin(hostname)` + `MDNS.addService("http", "tcp", 80)` fired once on `STA_GOT_IP`. The bridge becomes reachable as `<hostname>.local` on any LAN with Bonjour / avahi support. No new lib_dep (ESPmDNS ships with Arduino-ESP32).
- **Short hostname** : the STA / mDNS hostname is now plain `somfyrts2mqtt` (no MAC suffix). The AP SSID keeps the suffix (`somfyrts2mqtt-<chipId6>`) so two bridges entering setup mode in the same physical space remain distinguishable. A future iter can make the hostname configurable via the web UI for multi-bridge LANs.
- **TX power 8.5 dBm** : explicit `WiFi.setTxPower(WIFI_POWER_8_5dBm)` in both the STA path (right after `WiFi.mode(WIFI_STA)`) and the AP path (via tzapu's `setAPCallback`). Bypasses the ESP32-C3 Super Mini PA saturation that triggers AUTH_EXPIRE / association issues on some boards. Harmless on WROOM. Backported from `fix/c3-wifi-tx-power` (PR #20 on main).

**Out of scope:**
- GPIO long-press button to force AP. The 4-power-cycles recovery covers the inaccessible-box case without hardware change.
- Runtime STA disconnect → AP fallback. Pure Tasmota `WifiConfig 4` behavior : retry forever. Stable network access for remote control matters more than self-healing into an unreachable AP.
- Multiple stored networks (Tasmota's AP1 / AP2). One stored SSID is enough for a fixed-location box.
- Captive portal HTTPS. AP is open and short-lived ; plain HTTP is fine.
- WPS, SmartConfig, ESP-Touch, BLE provisioning, Improv-WiFi.
- Auto-MQTT-config from the portal. MQTT broker config stays in the admin UI, set after the box is on the LAN.

## Acceptance criteria
- [ ] Build clean on `esp32-c3-mini` and `esp32-wroom`.
- [ ] `pio check` zero defects, `pio test -e native` all green (new cases for the boot-counter state machine).
- [ ] HW : fresh-flashed box (`pio run -t erase`) boots straight into AP `somfyrts2mqtt-XXXXXX`. Phone joins → captive portal pop-up shows the form.
- [ ] HW : Save valid creds → reboot → STA connects → admin UI reachable at the LAN IP. Reboot a second time → STA reconnects directly (no AP).
- [ ] HW : box configured for SSID "A", power-cycled with SSID "A" turned off → keeps retrying STA forever, never AP. Re-enable SSID "A" → STA associates within the next retry window. No manual action required.
- [ ] HW : box on STA, 4 power-cycles within 5 s each → 4th boot lands in AP mode. Configure a different SSID via the portal → boots into the new STA on next reboot.
- [ ] HW : box on STA, admin UI WiFi form → enter new SSID + pass → 204 → reboot → STA connects on the new network.
- [ ] HW : box in AP mode, no save action for 5 min → auto-reboot → retries STA.
- [ ] HW : `ping somfyrts2mqtt.local` resolves and answers once the box is in STA mode. `http://somfyrts2mqtt.local/` opens the admin UI.
- [ ] HW : C3 Super Mini boards that previously hit AUTH_EXPIRE on the Freebox connect successfully with the 8.5 dBm clamp (validated on board #2).
- [ ] CI green on the PR.

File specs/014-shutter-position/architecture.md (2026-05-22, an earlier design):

# Architecture 014

## Touched modules

| File | Change |
|---|---|
| `include/nvs_store.h`, `src/nvs_store.cpp` | Extend `Remote` with `open_time_ms`, `close_time_ms`, `position`. Add `mqtt.topic` (root topic prefix) to `MqttConfig`. Tighten `is_valid_name()` to the new regex. NVS layout bump (acceptable per iter 014 wipe-on-flash). |
| `include/orchestrator.h`, `src/orchestrator.cpp` | Per-remote position state machine. New `set_position(N)`, `set_open_duration(ms)`, `set_close_duration(ms)`, `set_calibration_position(N)` entry points. 1 Hz tick driven from `loop()` updates estimates + enqueues Stop on intermediate target reached + publishes telemetry. |
| `include/mqtt.h`, `src/mqtt.cpp` | Replace `somfy2mqtt/<HEXID>/...` subscribe with `cmnd/<topic>/+/+` wildcard. New `publish_shutter_state(name, position, direction, target)`, `publish_sensor_aggregated()`, `publish_lwt(online)`. Subscribe + publish use `mqtt.topic` from NVS. Reconnect on topic change. |
| `src/web_ui.cpp` | Add `mqtt.topic` field to the broker form. Add `open_dur_s`, `close_dur_s` columns + `Position` cell + `Set Position` input per remote row. Name input gets the regex pattern attribute. |
| `include/shutter_state.h` | New pure-logic header for the position estimator (testable on native). |
| `test/test_shutter_state/` | New native tests for the estimator + name validator + topic-prefix validator. |

Files unchanged : `rf.cpp` / `rf.h` (short path stays as is ; long-press path was rolled back with iter 012), `wifi_manager.cpp`, `main.cpp` (except adding the orchestrator tick call).

## NVS layout extensions

`Remote` struct (currently `id`, `name`, `rolling_code`) gains :

```cpp
uint32_t open_time_ms;     // 0 = uncalibrated, otherwise duration of a full Open
uint32_t close_time_ms;    // 0 = use open_time_ms as a fallback, otherwise duration of a full Close
uint8_t  position;         // 0-100, last persisted snapshot
```

Persistence keyed under `remotes/<hex_id>/...` as today, with three new sub-keys.

`MqttConfig` (currently `host`, `port`, `user`, `pass`) gains :

```cpp
std::string topic;  // root topic prefix, default = "somfyrts2mqtt"
```

Stored under `mqtt/topic`.

## MQTT topic structure

Given `<topic>` = `mqtt.topic` from NVS (default `somfyrts2mqtt`) and `<name>` = a Remote's `name` :

**Subscribed (cmnd) :**

```
cmnd/<topic>/<name>/Open              ""              → orchestrator: open
cmnd/<topic>/<name>/Close             ""              → orchestrator: close
cmnd/<topic>/<name>/Stop              ""              → orchestrator: stop
cmnd/<topic>/<name>/Position          "<0-100>"       → orchestrator: move to N %
cmnd/<topic>/<name>/OpenDuration      "<seconds>"     → NVS update + ack
cmnd/<topic>/<name>/CloseDuration     "<seconds>"     → NVS update + ack
cmnd/<topic>/<name>/SetPosition       "<0-100>"       → NVS update (no RF)
```

Subscription pattern uses a single multi-level wildcard : `cmnd/<topic>/+/+`. The handler parses `<name>` and the trailing verb.

**Published (tele / stat) :**

```
tele/<topic>/LWT                       "Online"|"Offline"   retained, LWT="Offline"
tele/<topic>/SENSOR                    {JSON aggregated, see below}
stat/<topic>/<name>                    {JSON per remote, see below}
```

`tele/<topic>/SENSOR` payload (one entry per remote ; published 1 Hz during any motion + on every state transition) :

```json
{
  "kitchen_shutter": {"Position": 45, "Direction": 1, "Target": 100},
  "bedroom":         {"Position":  0, "Direction": 0, "Target":   0}
}
```

`stat/<topic>/<name>` payload (published after each cmnd as ack) :

```json
{"Position": 45, "Direction": 1, "Target": 100}
```

Or on a duration update :

```json
{"OpenDuration": 18.5, "CloseDuration": 20.2}
```

Or on error :

```json
{"error": "not calibrated"}
```

Convention :
- **Position** 0-100, where 0 = closed and 100 = open.
- **Direction** -1 = closing, 0 = stopped, 1 = opening (Tasmota convention).
- **Target** 0-100, the destination of the current or last motion.
- **OpenDuration / CloseDuration** float seconds (one decimal) on the wire.
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

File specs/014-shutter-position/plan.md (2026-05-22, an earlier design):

# Plan 014

## Order of operations

The work splits cleanly along module boundaries. Implementing in this order keeps the build green after each step :

1. **Position estimator** (`include/shutter_state.h`) + its native tests. Pure logic, no deps. Locks down the math.
2. **NVS extensions** (`Remote` + `MqttConfig` fields, name regex, topic regex). Native tests for the validators.
3. **MQTT layer rewrite** (`mqtt.cpp` / `mqtt.h`) : new topic subscribe pattern, new publish helpers, LWT, configurable root topic.
4. **Orchestrator state machine** : per-remote runtime, transitions, 1 Hz tick. Calls into the new MQTT helpers.
5. **Wiring in `main.cpp`** : call `orchestrator::tick()` from `loop()` once per second.
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

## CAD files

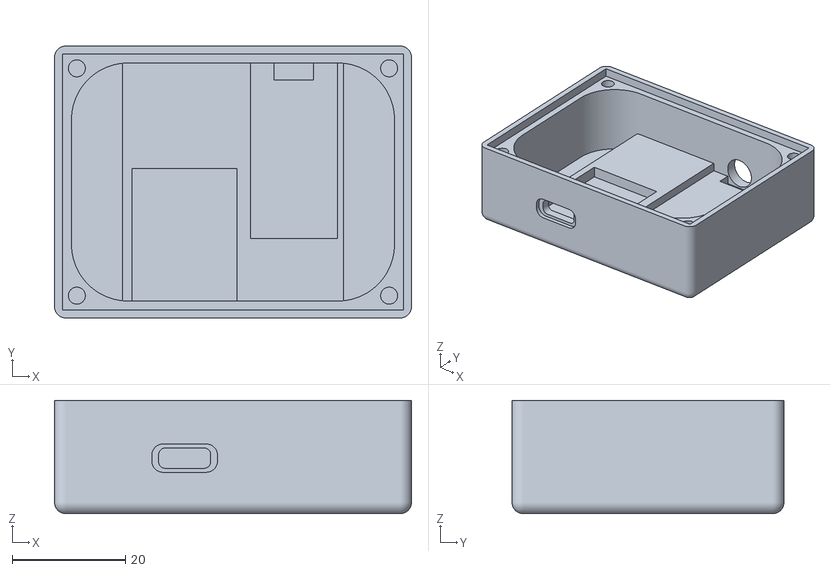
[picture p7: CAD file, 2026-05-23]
meca/somfyrts2mqtt_housing-box_housing.stl
63.0 x 48.0 x 20.0

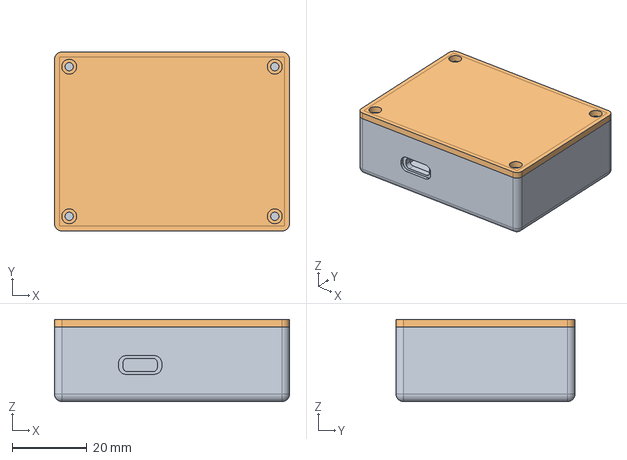
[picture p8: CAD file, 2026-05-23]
meca/somfyrts2mqtt_housing.FCStd
63.0 x 48.0 x 22.0 mm
cover

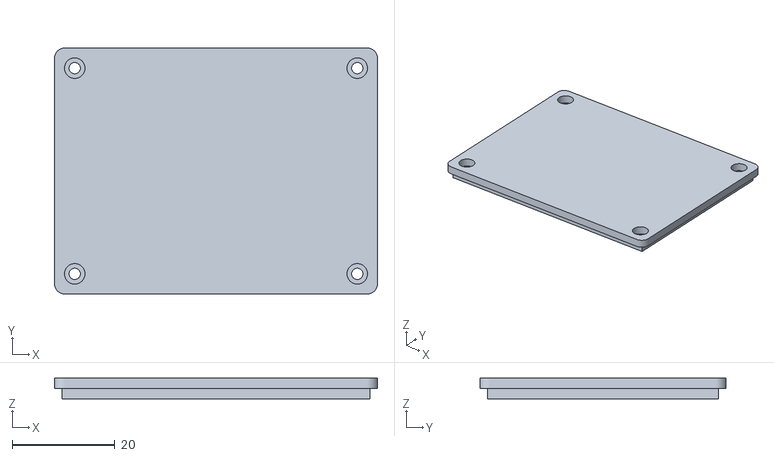
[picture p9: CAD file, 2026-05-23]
meca/somfyrts2mqtt_housing-box_cover.stl
63.0 x 48.0 x 4.00

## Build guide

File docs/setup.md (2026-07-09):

# Setup

End-to-end procedure from blank board to a working bridge on the LAN.

## Prerequisites

- PlatformIO Core (CLI) or PlatformIO IDE. Install with `pip install platformio` or via VSCode extension.
- A wired CC1101 (see [hardware.md](hardware.md)).
- A 2.4 GHz WiFi access point (WPA2-PSK recommended).
- A MQTT broker on the LAN (mosquitto, EMQX, HiveMQ, etc.). The broker can be set up later, the bridge tolerates `mqtt_connected=false` indefinitely.

## Build

No compile-time WiFi credentials needed. A fresh checkout builds straight into a captive-portal-enabled firmware.

```bash
git clone https://github.com/mchacher/somfyrts2mqtt.git
cd somfyrts2mqtt

# Optional : keep secrets.h empty (default) for AP-portal commissioning.
# OR pre-fill it for instant STA boot during dev (no AP step needed).
cp include/secrets.h.example include/secrets.h
$EDITOR include/secrets.h

# Build, type-check, run native tests
pio run
pio check
pio test -e native
```

## First flash

Connect the board over USB, then pick the env matching your board :

```bash
pio run -e esp32-c3-mini   -t upload -t monitor   # ESP32-C3 Super Mini
pio run -e esp32-s3-picybi -t upload -t monitor   # ESP32-S3 (PICYBI Radio Remote)
```

The serial monitor should log :

```
[boot] hello somfyrts2mqtt v0.1.0 reset_reason=POWERON(1)
[nvs] ready schema=1 remotes=0
[wifi] entering AP mode (force=0, ssid_empty=1)
[wifi] captive portal SSID=somfyrts2mqtt-AB12CD timeout=300s
```

If you see `cc1101 NOT responding` instead, jump to [troubleshooting](troubleshooting.md#cc1101-not-responding).

## Captive portal commissioning

With NVS empty (fresh flash), the bridge boots into SoftAP mode.

1. On your phone or laptop, join the open WiFi **`somfyrts2mqtt-<MAC>`** (the suffix matches the chip ID — visible in the boot log).
2. Most modern OSes pop up the captive portal automatically. If not, open `http://192.168.4.1/` in any browser.
3. The portal (tzapu / WiFiManager) shows a SSID dropdown (scan refresh button) + a password field.
4. Pick your home SSID, enter the password, click Save.
5. The bridge reboots into STA mode and joins your LAN.

Boot log on a successful first STA connect :

```
[wifi] mDNS up : somfyrts2mqtt.local (http :80)
[wifi] connected ip=192.168.0.75 rssi=-67 channel=6 in 3120ms
```

Open `http://somfyrts2mqtt.local/` (or the LAN IP) and the admin web UI loads. See [web-ui.md](web-ui.md) for the section-by-section tour.

## MQTT broker configuration

The admin UI's `MQTT broker` card asks for :

- **Host** — broker IP or DNS name (e.g. `192.168.0.230`)
- **Port** — usually `1883` (or `8883` for TLS, not supported yet)
- **User** / **Pass** — optional, empty for anonymous brokers
- **Topic** — Tasmota-style root topic. Empty = default `somfyrts2mqtt`. Set a distinct value (e.g. `somfyrts2mqtt-rdc`) if you run multiple bridges on the same broker

Save the form and the bridge reconnects to the broker. The `MQTT` pill in the Status card flips to green when connected.

## Add a Somfy remote

Each Somfy receiver pairs with a 24-bit "remote ID" + rolling code. The bridge invents a new virtual remote that you pair with the motor once.

1. In the admin UI, scroll to the **Remotes** card.
2. Bottom row : enter a 6-hex ID of your choice (e.g. `A1B2C3`) and a MQTT-safe name (`kitchen_shutter`, `bedroom`, `store_terrasse` — only letters, digits, `_`, `-`).
3. Click **Add**. The remote appears in the table with rolling code 0.
4. Put the motor in pair mode (long-press PROG on an already-paired remote OR press the P2 button on the motor head).
5. In the bridge UI, click the gear icon next to your new remote, then click **🔗 Prog**. The motor jogs to confirm pairing.

You can now send Up / Stop / Down from the UI buttons, or via MQTT (see [mqtt-api.md](mqtt-api.md)).

## Calibration (for position tracking)

Position tracking is optional but useful. To calibrate :

1. Click the gear icon next to a remote in the Remotes table → the Setup row expands.
2. Time how long the motor takes to fully open the shutter (stopwatch).
3. Same for full close (durations can differ on some motors).
4. Enter the values in the **Calibration** fields. Click outside to commit (auto-save on blur).
5. For awnings ("store banne") tick the **Invert Up/Down** checkbox — the Open command now extends the awning instead of retracting it.

The bridge now reports Position (0-100 %) live during motion, both in the UI and in MQTT `tele/<root>/SENSOR`.

## Reconfigure WiFi (without re-flashing)

Three paths :

1. **Web UI** — Status card shows the SSID. The WiFi card has a SSID + Password form ; Save and reconnect. Use when the LAN is still working.
2. **Captive portal again** — visit the admin UI, factory-reset, the bridge reboots into the captive portal.
3. **4-power-cycle recovery** — for a bridge that you cannot reach (wrong WiFi creds, router changed, lost LAN access) :
   - Cycle power on the bridge 4 times in less than 5 seconds each
   - On the 4th boot, the boot counter reaches the AP threshold and the bridge enters the captive portal automatically
   - Same workflow as first-time commissioning

The counter resets after 5 s of stable WiFi association ; if WiFi is down, it never resets — exactly the case the recovery is meant to fix.

## Updating firmware over the air

After the initial USB flash, every subsequent update can be done over WiFi -- no cable needed.

### From a GitHub Release (recommended for end users)

1. Go to <https://github.com/mchacher/somfyrts2mqtt/releases/latest>.
2. Download the `.bin` **matching your board** — `somfyrts2mqtt-<version>-esp32-c3-mini.bin` for the C3 Super Mini, `somfyrts2mqtt-<version>-esp32-s3-picybi.bin` for the PICYBI ESP32-S3. The two are not interchangeable. The **Variant** field in the Status card tells you which board you are running.
3. Open the admin UI → **Update firmware** section.
4. Click *Choose File*, pick the `.bin`, click **Upload & reboot**.
5. Two confirmation dialogs (the second warns that a bad binary can brick the device). Click OK on both.
6. The progress bar fills as the bridge streams chunks into the OTA partition. On 100 %, the bridge reboots and the page auto-reloads after ~8 s.
7. The Status card shows the new version.

If the upload fails (wrong file, truncated, corrupted) the bridge stays on the previous firmware and the UI displays the error returned by the `Update` library. No partition switch happens until the new image is fully written and the MD5 matches. A binary built for **another chip** (e.g. a C3 `.bin` on an S3 board) is rejected up front with a clear "firmware targets ESP32-C3, this bridge is ESP32-S3" message — before any flash write — so a mismatch never even reaches the partition.

You can verify the binary integrity before uploading using the SHA256 sums attached to each Release :

```bash
shasum -a 256 -c sha256sums.txt
```

### Developer workflow (ArduinoOTA)

For repeated pushes during development, PlatformIO can speak the espota protocol over mDNS directly :

```bash
pio run -e esp32-c3-mini -t upload \
    --upload-port somfyrts2mqtt.local \
    --upload-flags "--auth=<your OTA_PASSWORD>"
```

The password is the `OTA_PASSWORD` macro from `include/secrets.h` (defaults to `"somfy"` ; change it locally). ArduinoOTA advertises `_arduino._tcp` on port 3232, automatically discovered by PlatformIO.

For convenience, add a dedicated env in `platformio.ini` :

```ini
[env:esp32-c3-mini-ota]
extends = env:esp32-c3-mini
upload_protocol = espota
upload_port     = somfyrts2mqtt.local
upload_flags    = --auth=<your OTA_PASSWORD>
```

Then `pio run -e esp32-c3-mini-ota -t upload` is enough.

End users never need ArduinoOTA -- WebOTA is the supported path.

### Cutting a new release (maintainer)

The release publishing flow (tag → CI builds binaries → attaches them to a GitHub Release with auto-generated, label-categorised notes) is documented in [docs/releasing.md](releasing.md). The firmware version displayed in the Status card is derived from `git describe` at build time, so the only manual step at release time is `git tag -a vX.Y.Z` + `git push`.

## Factory reset

Two ways :

- **Web UI** — Danger zone → Factory reset → confirm twice. NVS is wiped and the bridge reboots into AP mode.
- **`pio run -t erase`** — wipes the entire flash (NVS + app). Re-upload firmware after.

NVS is wiped, MQTT broker / remotes / WiFi credentials all lost. The bridge starts fresh in captive portal mode.

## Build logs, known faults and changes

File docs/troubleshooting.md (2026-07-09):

# Troubleshooting

Common issues and verified fixes, in rough order of frequency.

## AUTH_EXPIRE loop on ESP32-C3 Super Mini

**Symptom :** the serial monitor spams `[wifi] disconnected reason=2 (AUTH_EXPIRE)` once per second, never reaches `connected ip=...`.

**Root cause :** the C3 Super Mini PA is miscalibrated above ~15 dBm on some boards. The saturated TX corrupts the WPA2 4-way handshake and the AP times out the auth state.

**Fix :** the firmware already calls `WiFi.setTxPower(WIFI_POWER_8_5dBm)` in `wifi_manager.cpp::init()`. No user action needed since v0.1.0.

If you still hit AUTH_EXPIRE despite the clamp :
1. Check the LED is on, board is powered (not a brown-out).
2. Verify the password (no typo, no leading space).
3. Use the 4-power-cycle recovery to re-enter the captive portal and double-check the credentials.

References : [arduino-esp32 issue #6767](https://github.com/espressif/arduino-esp32/issues/6767), [Arduino forum thread #1264358](https://forum.arduino.cc/t/esp32-c3-fails-to-connect-to-wifi-reason-2-auth-expired/1264358).

## CC1101 not responding

**Symptom :** boot log shows `[rf] cc1101 NOT responding (part=0x00 version=0x00)` or `part=0xFF version=0xFF`.

| Reading | Diagnosis |
|---|---|
| `part=0x00 version=0x00` | MISO held LOW. Soldering joint on MISO or VDD ; or chip not powered |
| `part=0xFF version=0xFF` | MISO floating. Chip not responding at all (likely dead) |
| `part=0x00 version=0x14` (or `0x04`, `0x07`) | Actually responding. Should not show NOT-responding ; if it does there is a firmware issue |

**Things to try :**

1. **Swap the CC1101 module** — clones have a 5-15 % failure rate. Try another one.
2. **Verify VCC** at the CC1101 module's VCC pin with a multimeter — must be ~3.3 V stable.
3. **Verify continuity** on the four SPI lines (SCK, MISO, MOSI, CSN) between the ESP32 GPIO and the CC1101 pin — < 1 Ω.
4. **Shorten the Dupont wires** to ≤ 5 cm. Long thin wires degrade SPI signals on borderline modules.
5. **Add 100 nF decoupling** across CC1101 VCC / GND, close to the chip.
6. **Add a 10 kΩ pull-up on MISO** to 3.3 V — fixes some clones whose MISO is too slow to settle.

**Note :** the cheap CC1101 clones have a real defect rate (~5-15 % out of the box in our sample). A module that does not respond on one ESP32 typically does not respond on any other ESP32 either -- it is the module that is dead, not a wiring / coupling issue. Swap it for another one rather than chase ghosts.

## mDNS not resolving

**Symptom :** `ping somfyrts2mqtt.local` returns "unknown host" but the bridge is on the LAN.

**Per OS :**

| OS | mDNS support |
|---|---|
| macOS / iOS | Built-in (Bonjour). Works out of the box |
| Windows 10 / 11 | Built-in (since Win10 1903). Works |
| Linux | Needs `avahi-daemon` — install with `sudo apt install avahi-daemon` then `sudo systemctl enable --now avahi-daemon` |
| Android | Some launchers / browsers do not resolve `.local`. Use the LAN IP shown in the bridge's Status card |

**Workaround :** the boot log prints the DHCP-assigned IP — use that directly (`http://192.168.0.75/`).

## Position drifts over time

**Symptom :** after several runs, the reported Position is off by 10-20 % from the visible shutter state.

**Why :** time-based estimation drifts due to motor wear, load variation (wind on awnings), and especially **external operation** (physical wall remote, another Somfy controller). The bridge has no way to observe those — Somfy RTS is unidirectional.

**Mitigation :**

1. The bridge auto-recalibrates on every **full Open** (snap Position to 100) and **full Close** (snap to 0). Do a full cycle now and then.
2. Manual resync via the UI : click the **🎯 Sync** button in the Setup row, enter the actual percentage, save. NVS updated, no RF.
3. Via MQTT : `cmnd/<root>/<name>/SetPosition <value>`.

## Open and Close inverted (awnings)

**Symptom :** `cmnd/.../Open` retracts the awning instead of extending it. `Close` extends.

**Root cause :** Somfy "store banne" motors are typically paired so that the Up button retracts (which feels like "close"). The default convention (`Up = Open = 100`) does not match the user mental model for awnings.

**Fix :** in the Remotes table, click the ⚙ gear on the row, tick **Invert Up/Down (awnings)** in the Setup sub-row. The bridge now swaps Up ↔ Down at the RF layer ; `Open` extends, `Close` retracts. Position stays in user space (100 = visually open).

## 4-power-cycle recovery does not trigger AP

**Symptom :** you cycle the power four times but the bridge keeps trying STA, never enters AP.

**Diagnosis :** the boot counter is reset between cycles because the bridge reaches `WL_CONNECTED` and stable uptime in less than 5 s between two cuts.

**Fix :** cut the power **before** the 5 s stable-uptime window. If the bridge is associating fast on your network, your cycle window is 0-5 s after each power-on. Keep cycles tight.

If the bridge is failing to connect (wrong creds), the counter never resets, so 4 cycles suffice no matter the timing.

To verify : watch the serial monitor for `[wifi] boot counter X/4` at each boot. If you see `boot counter reset (stable uptime reached)`, you waited too long.

## Erase command does not erase the remote

**Symptom :** click 🗑 Erase (7 s long press) on remote A, then 🔗 Prog brief on the same remote A → the remote stays paired.

**Root cause :** Somfy receivers **exclude the issuing remote** from the deletion candidates. You cannot self-erase from the same remote that issued the 7 s PROG.

**Fix :** the Erase workflow needs **two** paired remotes :

1. Click 🗑 Erase on remote A (SOURCE) — the 7 s long-press puts the motor in deletion mode.
2. Within 10 s of the motor jog, click 🔗 Prog briefly on remote B (TARGET) — remote B is now erased.

The web UI prompts a confirmation dialog with this workflow when you click Erase.

## Bridge keeps rebooting / brown-out

**Symptom :** boot log says `reset_reason=BROWNOUT` repeatedly.

**Root cause :** the 3.3 V LDO sags under load (WiFi TX bursts, MQTT TLS handshake, RF emission). Common on cheap C3 boards powered through a thin USB cable.

**Fix :**
1. Use a **5 V / 2 A wall adapter** (not a laptop USB port or a hub).
2. Switch to a **short, thick USB cable**.
3. Add a **100 µF electrolytic cap** + a **100 nF ceramic** across the C3's 3V3 / GND pins, close to the chip.

## How to read serial logs reliably

USB-CDC over the C3 Super Mini is sometimes flaky (drops bytes during high RX). Workarounds :

- Use `pio device monitor --raw` and grep for the relevant tag (`[wifi]`, `[rf]`, etc.).
- Power the bridge from a wall adapter (not the same USB you read logs on) — separates power supply and serial.
- If still unreliable, drop a temporary `MDNS.addService("debug", "tcp", 23)` + a Telnet server, and read logs over WiFi.

On the **ESP32-S3 (PICYBI)** the USB-Serial/JTAG re-enumerates on the host after each reset, so the **boot log is lost** unless a terminal is already attached — a plain `pio device monitor` started after boot shows nothing until the next log line. To capture boot output, build with `-DWAIT_FOR_SERIAL` (the firmware then waits up to 3 s for the CDC host before logging). It is off by default so headless production boots are not delayed.

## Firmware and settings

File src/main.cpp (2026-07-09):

/**
 * @file main.cpp
 * @brief Firmware entry point. Boots every module and wires the dispatch chain.
 */
#include <Arduino.h>
#include <esp_system.h>
#include "logger.h"
#include "mqtt.h"
#include "nvs_store.h"
#include "orchestrator.h"
#include "rf.h"
#include "secrets.h"
#include "web_ui.h"
#include "wifi_manager.h"

/// Decode the last reset reason into a short tag for the boot log.
/// Critical for diagnosing reset loops : BROWNOUT vs TASK_WDT vs PANIC vs
/// POWERON each point at different root causes (LDO marginal, blocking
/// callback, exception, or fresh boot).
static const char* reset_reason_tag(esp_reset_reason_t r) {
  switch (r) {
    case ESP_RST_POWERON:   return "POWERON";
    case ESP_RST_EXT:       return "EXT";        // external pin (RESET button)
    case ESP_RST_SW:        return "SW";         // ESP.restart()
    case ESP_RST_PANIC:     return "PANIC";      // exception / abort()
    case ESP_RST_INT_WDT:   return "INT_WDT";    // interrupt watchdog
    case ESP_RST_TASK_WDT:  return "TASK_WDT";   // task watchdog
    case ESP_RST_WDT:       return "WDT";
    case ESP_RST_DEEPSLEEP: return "DEEPSLEEP";
    case ESP_RST_BROWNOUT:  return "BROWNOUT";   // LDO / supply marginal
    case ESP_RST_SDIO:      return "SDIO";
    default:                return "?";
  }
}

/**
 * @brief Seed the broker config from secrets.h if NVS does not have one yet.
 *
 * One-shot helper used the very first time a board boots. After that, the
 * web UI is the canonical place to edit the broker config.
 */
static void bootstrap_mqtt_from_secrets() {
  if (!nvs_store::ready()) return;
  const nvs_store::MqttConfig current = nvs_store::get_mqtt();
  if (!current.host.empty()) return;
  nvs_store::MqttConfig seed;
  seed.host = MQTT_BROKER_HOST;
  seed.port = MQTT_BROKER_PORT;
  seed.user = MQTT_BROKER_USER;
  seed.pass = MQTT_BROKER_PASS;
  if (nvs_store::set_mqtt(seed)) {
    logger::info("boot", "seeded MQTT config from secrets.h host=%s port=%u",
                 seed.host.c_str(), seed.port);
  }
}

void setup() {
  Serial.begin(115200);
#if defined(WAIT_FOR_SERIAL)
  // Opt-in dev aid for native-USB boards (C3/S3): the USB-Serial/JTAG CDC
  // re-enumerates on the host after a reset, so the boot log is otherwise lost
  // before the terminal re-attaches. Off by default -- a fixed multi-second
  // wait would slow every headless production boot (power-loss recovery).
  // Build with `-DWAIT_FOR_SERIAL` to capture boot output over USB.
  for (unsigned long t = millis(); !Serial && millis() - t < 3000UL;) delay(10);
#endif
  delay(200);
  Serial.println();
  const esp_reset_reason_t rr = esp_reset_reason();
  logger::info("boot", "hello somfyrts2mqtt v%s reset_reason=%s(%d)",
               FW_VERSION, reset_reason_tag(rr), static_cast<int>(rr));
  nvs_store::init();
  bootstrap_mqtt_from_secrets();
  rf::init();
  wifi::init();
  mqtt::init();
  orchestrator::init_runtimes();
  // Give WiFi up to 15 s to get an IP so the web_ui log can show the real
  // address. The cold-boot path scans + connects in ~3-8 s on a healthy board;
  // we allow more headroom for boards with a degraded RF chain.
  // Calling wifi::loop() here lets the sticky-bad-BSSID recovery kick in
  // during the boot grace window (otherwise the rescan would only trigger
  // once setup() returns and the main loop starts).
  for (int i = 0; i < 150 && !wifi::is_connected(); ++i) {
    wifi::loop();
    delay(100);
  }
  web_ui::init();
}

void loop() {
  
  wifi::loop();
  mqtt::loop();
  // Drain at most one queued web-UI command per tick. RF emissions take
  // 360 ms (regular) to 7 s (Erase PROG 7 s) -- doing one per tick keeps
  // the WiFi/MQTT loops responsive in between.
  orchestrator::process_queue();

  // 1 Hz position tick (iter 014). Updates live position estimates for
  // any shutter currently in motion, enqueues Stop on intermediate-target
  // reached, and triggers SENSOR telemetry.
  static unsigned long s_last_tick_ms = 0;
  const unsigned long now = millis();
  if (now - s_last_tick_ms >= 1000UL) {
    s_last_tick_ms = now;
    orchestrator::tick(now);
  }

  delay(20);
}

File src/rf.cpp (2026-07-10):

/**
 * @file rf.cpp
 * @brief CC1101 init + real Somfy RTS emission. See rf.h.
 */
#include "rf.h"

#include <Arduino.h>
#include <ELECHOUSE_CC1101_SRC_DRV.h>
#include <SomfyRemote.h>

#include "config.h"
#include "logger.h"

namespace rf {

  static bool s_ready = false;

  /// CC1101 PARTNUM status register address (expected 0x00 for CC1101).
  static constexpr uint8_t CC1101_REG_PARTNUM = 0x30;
  /// CC1101 VERSION status register address (0x14 typical, 0x04 / 0x07 on clones).
  static constexpr uint8_t CC1101_REG_VERSION = 0x31;

  /// CC1101 PA power in dBm. Somfy remotes are ~+9 dBm; +10 gives a small edge.
  static constexpr uint8_t CC1101_PA_DBM = 10;

  /// CC1101 modulation index for ASK/OOK (per SmartRC-CC1101 lib mapping).
  static constexpr uint8_t CC1101_MOD_OOK = 2;

  /// CC1101 PKT_FORMAT for asynchronous serial mode (carrier gated by GDO0 level).
  static constexpr uint8_t CC1101_PKT_FORMAT_ASYNC = 3;

  bool init() {
    // Step 1: register our custom SPI pinout.
    ELECHOUSE_cc1101.setSpiPin(CC1101_SCK, CC1101_MISO, CC1101_MOSI, CC1101_CSN);

    // Step 2: Init() must run BEFORE any SpiReadStatus call. It is what calls
    // SPI.begin(SCK, MISO, MOSI, -1) with our custom pins + Reset() the chip
    // + writes the default register config.
    ELECHOUSE_cc1101.Init();

    // Step 3: read raw status registers for the ping + diagnostic log.
    const uint8_t part    = ELECHOUSE_cc1101.SpiReadStatus(CC1101_REG_PARTNUM);
    const uint8_t version = ELECHOUSE_cc1101.SpiReadStatus(CC1101_REG_VERSION);
    const bool ok = (version > 0x00) && (version < 0xFF);
    if (!ok) {
      logger::err("rf",
                  "cc1101 NOT responding (part=0x%02X version=0x%02X) -- check wiring/power",
                  static_cast<unsigned>(part), static_cast<unsigned>(version));
      s_ready = false;
      return false;
    }
    logger::info("rf", "cc1101 ok part=0x%02X version=0x%02X",
                 static_cast<unsigned>(part), static_cast<unsigned>(version));

    // Step 4: configure for Somfy RTS OOK emission.
    //   - 433.42 MHz carrier
    //   - ASK/OOK modulation
    //   - PA +10 dBm
    //   - No preamble / sync word (we drive the raw RF level via GDO0)
    //   - PKT_FORMAT = 3 (async serial) -> CC1101 keys the carrier from GDO0
    ELECHOUSE_cc1101.setMHZ(SOMFY_FREQ_MHZ);
    ELECHOUSE_cc1101.setModulation(CC1101_MOD_OOK);
    ELECHOUSE_cc1101.setPA(CC1101_PA_DBM);
    ELECHOUSE_cc1101.setSyncMode(0);
    ELECHOUSE_cc1101.setPktFormat(CC1101_PKT_FORMAT_ASYNC);
    ELECHOUSE_cc1101.SetTx();

    // Step 5: GDO0 is the modulation input -- we drive it directly with
    // digitalWrite() during emission. Start at LOW (no carrier).
    pinMode(CC1101_GDO0, OUTPUT);
    digitalWrite(CC1101_GDO0, LOW);

    s_ready = true;
    logger::info("rf",
                 "cc1101 OOK ready freq=%.2f MHz pa=%u dBm mod=%u pkt_format=%u",
                 static_cast<double>(SOMFY_FREQ_MHZ),
                 static_cast<unsigned>(CC1101_PA_DBM),
                 static_cast<unsigned>(CC1101_MOD_OOK),
                 static_cast<unsigned>(CC1101_PKT_FORMAT_ASYNC));
    return true;
  }

  bool send_somfy(uint32_t remote_id, uint16_t rolling_code, uint8_t button, int repeat) {
    if (!s_ready) return false;
    if (button == 0) return false;

    // We pass nullptr for RollingCodeStorage: the orchestrator already
    // persisted the rolling code in NVS (persist-before-emit). The lib
    // never dereferences the storage when sendCommandWithCode() is used.
    SomfyRemote remote(CC1101_GDO0, remote_id, nullptr);
    remote.setup();
    remote.sendCommandWithCode(static_cast<::Command>(button), rolling_code, repeat);

    logger::info("rf", "tx id=%06X code=%u button=0x%02X repeat=%d",
                 static_cast<unsigned>(remote_id & 0xFFFFFFu),
                 static_cast<unsigned>(rolling_code),
                 static_cast<unsigned>(button),
                 repeat);
    return true;
  }

  // === iter 022 : 80-bit "Toggle" frame (single-button gate) ===============
  //
  // Somfy's Toggle command lives in an 80-bit RTS frame that the 56-bit
  // Legion2 library cannot build. We encode + bit-bang it ourselves. The frame
  // format and OOK timing mirror rstrouse/ESPSomfy-RTS (the Somfy RTS wire
  // protocol; SYMBOL = 640 us, wake-up pulse, 4-SYMBOL hardware-sync pulses,
  // a software sync, then Manchester data MSB-first).

  namespace {
    constexpr int SOMFY_SYMBOL_US = 640;

    /// 80-bit extension checksum over the 3 trailing bytes (nibble XOR).
    uint8_t calc80_checksum(uint8_t b7, uint8_t b8, uint8_t b9) {
      uint8_t cs = static_cast<uint8_t>(((b7 & 0xF0) >> 4) ^ ((b8 & 0xF0) >> 4));
      cs ^= static_cast<uint8_t>((b9 & 0xF0) >> 4);
      cs ^= static_cast<uint8_t>(b7 & 0x0F);
      cs ^= static_cast<uint8_t>(b8 & 0x0F);
      return static_cast<uint8_t>(cs & 0x0F);
    }

    /// frame[7] encodes the transmission index; wraps like ESPSomfy.
    uint8_t encode80_byte7(uint8_t start, int repeat) {
      while ((repeat * 4) + start > 255) repeat -= 15;
      return static_cast<uint8_t>(start + (repeat * 4));
    }

    /// Set the 3 plain (non-obfuscated) extension bytes for the Toggle command.
    void set_toggle_ext(uint8_t* f, int tx_index) {
      f[7] = encode80_byte7(196, tx_index);
      f[8] = 0x00;
      f[9] = static_cast<uint8_t>(0x10 | calc80_checksum(f[7], f[8], f[9]));
    }

    /// Bit-bang one 80-bit frame on GDO0 (carrier keyed by the CC1101 in OOK).
    void tx_frame_80(const uint8_t* f, int hw_sync, bool wakeup) {
      if (wakeup) {
        digitalWrite(CC1101_GDO0, HIGH); delayMicroseconds(10920);
        digitalWrite(CC1101_GDO0, LOW);  delayMicroseconds(7357);
      }
      for (int i = 0; i < hw_sync; i++) {
        digitalWrite(CC1101_GDO0, HIGH); delayMicroseconds(4 * SOMFY_SYMBOL_US);
        digitalWrite(CC1101_GDO0, LOW);  delayMicroseconds(4 * SOMFY_SYMBOL_US);
      }
      // Software sync.
      digitalWrite(CC1101_GDO0, HIGH); delayMicroseconds(4850);
      digitalWrite(CC1101_GDO0, LOW);  delayMicroseconds(SOMFY_SYMBOL_US);
      // 80 Manchester data bits, MSB first. 1 = low-then-high, 0 = high-then-low.
      int last = 0;
      for (int i = 0; i < 80; i++) {
        const int bit = (f[i / 8] >> (7 - (i % 8))) & 1;
        if (bit) {
          digitalWrite(CC1101_GDO0, LOW);  delayMicroseconds(SOMFY_SYMBOL_US);
          digitalWrite(CC1101_GDO0, HIGH); delayMicroseconds(SOMFY_SYMBOL_US);
          last = 1;
        } else {
          digitalWrite(CC1101_GDO0, HIGH); delayMicroseconds(SOMFY_SYMBOL_US);
          digitalWrite(CC1101_GDO0, LOW);  delayMicroseconds(SOMFY_SYMBOL_US);
          last = 0;
        }
      }
      if (last == 0) digitalWrite(CC1101_GDO0, HIGH);  // terminate a trailing 0
      digitalWrite(CC1101_GDO0, LOW);
    }
  }  // namespace

  bool send_toggle(uint32_t remote_id, uint16_t rolling_code, int repeat) {
    if (!s_ready) return false;
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

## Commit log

2026-05-20 chore: initial scaffold
    PlatformIO project for ESP32-C3 Super Mini + CC1101 module bridging
    Somfy RTS to MQTT. Mirrors the zigbee2mqtt pattern: dumb RF bridge,
    all home automation logic stays in Sowel.
    Contains:
    - platformio.ini (ESP32-C3, Arduino framework, Legion2/Somfy_Remote_Lib + LSatan/SmartRC-CC1101)
    - include/config.h (CC1101 pinout, MQTT topic prefix)
    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
2026-05-20 docs(spec): add iter roadmap and iter 001 (wifi + logger) spec
    Roadmap: 7 iterations from wifi+logger bootstrap (001) to web UI
    pairing (007). Iters 002-007 are stubs to be detailed at start of
    their respective iteration; iter 001 has full spec/architecture/plan.
    Iter 001 sets up two foundation modules:
    - logger (namespace logger, Serial.printf wrapper with [tag] prefix)
    - wifi (non-blocking connect + auto-reconnect via ESP32 events)
    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
2026-05-20 feat(wifi): wifi + logger modules (iter 001)
    - logger module (namespace logger): info/warn/err with [tag] prefix
    - wifi_manager: non-blocking connect + auto-reconnect via ESP32 events
    - secrets.h template committed, secrets.h gitignored
    Ref spec 001-wifi-logger. Build clean (0 warnings, 0 errors).
    [main.cpp]
2026-05-20 docs: switch project to English + apply Doxygen convention
    Switch all written content to English (code, comments, specs,
    CLAUDE.md, SKILL.md). Conversation with maintainer can stay French
    but no FR in committed artifacts.
    Add Doxygen comment convention: every header and public symbol gets
    a Doxygen block (@brief, @param, @return, @note). Implementation
    files keep only inline comments for non-obvious why-decisions.
    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
2026-05-20 build: cppcheck + native test env + FW_VERSION macro
    - Shared [common] section exposes FW_VERSION and -Wall.
    - Firmware env: check_tool=cppcheck with severity high+medium,
    third-party packages skipped, sane enable flags.
    - New [env:native] platform for host-side unit tests (Unity).
    Firmware env has test_ignore=test_* so native tests do not
    attempt to cross-compile.
    - Sample test/test_smoke/test_main.cpp serves as a template for
    the real native tests added from iter 002 onwards.
    Local run: pio run / pio check / pio test -e native all green.
    [test_main.cpp]
2026-05-20 feat(iter 002): nvs_store (#6)
    * docs(spec): expand iter 002 (nvs_store) to full spec/architecture/plan
    Persist MQTT broker config and up to 16 Somfy virtual remotes in
    ESP32 NVS via Arduino's Preferences. Pure-logic helpers (hex
    format, validation, index manipulation) covered by native tests.
    CRUD wiring delegates to Preferences and is exercised at boot via
    the diagnostic log.
    * feat(nvs): nvs_store module + native tests (iter 002)
    Persistent store for MQTT broker config and up to 16 Somfy virtual
    remotes, backed by Arduino's Preferences (namespace "somfy"). Pure
    helpers (hex format/parse, validation, CSV index manipulation) are
    inline in the header so native unit tests cover them withou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
    [main.cpp, test_main.cpp]
2026-05-20 feat(iter 003): mqtt client (#7)
    * docs(spec): expand iter 003 (mqtt client) to full spec/architecture/plan
    MQTT client with non-blocking reconnect, subscribe to
    somfy2mqtt/+/set, dispatch parsed commands to a handler (default
    logs only; iter 004 replaces it with the orchestrator). Bridge
    presence via retained somfy2mqtt/bridge/state + LWT. Publish API
    exposed for iter 004 (publish_state, publish_rolling_code).
    Lib: knolleary/PubSubClient. Bootstrap from secrets.h until iter 007
    introduces the web UI.
    * feat(mqtt): MQTT client + bridge presence + command dispatch (iter 003)
    Connects to the broker using the MQTT config persisted by iter 002.
    Subscribes to somfy2mqtt/+/set, parses payloads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
    [main.cpp, test_main.cpp]
2026-05-20 feat(iter 007): web UI MVP (#8)
    * docs(spec): expand iter 007 (web UI MVP); rename folder
    Web UI MVP for local LAN config: status, MQTT broker editor,
    remotes CRUD, factory reset. Inline HTML/CSS/JS in PROGMEM, no
    LittleFS, vanilla JS, no auth.
    Out of scope for this iter: AP fallback, WiFi config, command
    buttons (need iter 004), pairing PROG flow (needs iter 006).
    Folder renamed from 007-web-ui-pairing to 007-web-ui to reflect
    the broader MVP scope.
    * feat(web): web UI MVP for LAN config (iter 007)
    Embedded AsyncWebServer on port 80 (STA mode) serving a single-page
    UI and a JSON REST API. Replaces the secrets.h MQTT bootstrap as
    the source of truth: the user edits the broker + remotes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
    [main.cpp, web_ui.cpp]
2026-05-20 feat(iter 004): rf stub + orchestrator (#9)
    * docs(spec): expand iter 004 (rf stub + orchestrator) to full spec
    End-to-end chain: MQTT cmd -> NVS lookup -> persist rolling code ++
    -> rf::send_somfy (stub) -> publish state+rolling_code retained.
    Persist-before-emit pattern (rolling code committed to NVS before
    the RF call) avoids replay on reboot. RF stub will be swapped for
    the real CC1101 emission in iter 006 without touching the rest.
    Test remotes are added via the web UI (iter 007), not via a
    firmware seed fixture as the original plan had it.
    * feat(rf,orch): rf stub + orchestrator wiring the dispatch chain (iter 004)
    End-to-end chain now runs on the firmware:
    MQTT receive somfy2m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
    [main.cpp, rf.cpp, test_main.cpp]
2026-05-20 feat(iter 008): multi-board (ESP32-C3 + ESP32 WROOM) (#10)
    * feat(build): multi-board support (ESP32-C3 + ESP32 WROOM) (iter 008)
    The same source tree now builds for two boards. Pinout is selected
    at compile time from the target chip via CONFIG_IDF_TARGET_*; the
    rest of the firmware is already portable.
    Triggered by the original C3 Super Mini being damaged during
    iter 005 HW debug; the project keeps moving on the spare
    NodeMCU-32S.
    - platformio.ini: introduce [firmware_base] shared section + new
    [env:esp32-wroom] env that extends it. The existing
    [env:esp32-c3-mini] keeps its C3-specific USB-CDC flags.
    - include/config.h: #if CONFIG_IDF_TARGET_ESP32C3 / #elif
    CONFIG_IDF_TARGET_ESP32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
2026-05-20 feat(wifi): Tasmota-style scan + pin best BSSID + NVS hint (iter 009) (#11)
    WiFi connect goes from ~12 s (default begin against a mesh of multiple
    APs sharing the SSID) to ~3 s in steady state.
    How it works:
    - init() reads an NVS "wifi hint" {ssid, bssid, channel}. If present
    and the SSID matches WIFI_SSID, calls WiFi.begin(ssid, pass, channel,
    bssid) directly. No scan, connect in ~2-3 s.
    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
2026-05-20 feat(iter 005): cc1101 init + PARTNUM/VERSION ping (#12)
    * docs(spec): expand iter 005 (cc1101 init + ping) to full spec
    Replace the iter 004 stub of rf::init() with real CC1101 setup:
    configure SPI pins, ping the PARTNUM/VERSION status registers,
    calibrate to 433.42 MHz. No frame emission yet (iter 006).
    Non-fatal init failure: if the chip doesn't respond, log the raw
    register values + 'check wiring' hint and keep the firmware running
    (WiFi/MQTT/web UI still useful).
    * feat(rf): real CC1101 init + PARTNUM/VERSION ping on 433.42 MHz (iter 005)
    The stubbed rf::init from iter 004 is replaced with a real CC1101
    bring-up: register the custom SPI pinout, run the lib's Init() so SPI
    is actuall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
    [rf.cpp]
2026-05-21 feat(mqtt): Tasmota-style hardening -- timeouts, backoff, decoded state (iter 010) (#13)
    Triggered by the recent subnet-isolation case where the C3 spammed
    reconnect attempts every 5 s with the 3 s default TCP timeout and
    logged "rc=-2" with no human-readable explanation.
    Changes:
    - init(): client.setSocketTimeout(15) and client.setKeepAlive(60).
    The 3 s default TCP timeout is too tight for flaky residential
    networks. 60 s keep-alive cuts PINGREQ traffic 4x and tolerates
    brief broker hiccups.
    - loop(): exponential backoff between reconnect attempts. Starts at
    5 s (unchanged for healthy networks), doubles on failure, caps at
    60 s. Resets to 5 s after a successful connect (and on di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
    [test_main.cpp]
2026-05-21 feat(rf): real Somfy RTS emission via Legion2 lib + CC1101 OOK (iter 006) (#14)
    The stubbed rf::send_somfy from iter 004 is replaced with a real
    Somfy RTS frame emission. After this iteration the firmware is
    functionally complete: an MQTT command goes end-to-end MQTT ->
    orchestrator -> CC1101 -> motor.
    - rf::init(): after the PARTNUM/VERSION ping, configure the CC1101
    for asynchronous OOK at 433.42 MHz: setModulation(2), setPA(10),
    setSyncMode(0), setPktFormat(3), SetTx(). GDO0 (= GPIO10) is set
    as OUTPUT -- the carrier is keyed directly by its level.
    - rf::send_somfy(id, code, button): construct a transient SomfyRemote
    on CC1101_GDO0 and call sendCommandWithCode(button, co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
    [rf.cpp, test_main.cpp]
2026-05-21 feat(iter 011): per-remote command buttons in web UI (#15)
    * feat(web): per-remote command buttons UP/STOP/DOWN/PROG (iter 011)
    Add four icon buttons (Up, Stop, Down, Pair) on each Remotes row of
    the web UI. Each click POSTs to a new REST endpoint that calls
    orchestrator::handle_command() directly -- no MQTT round-trip, so
    the buttons keep working when the broker is unreachable (useful for
    the pairing workflow with an existing Somfy remote).
    - New endpoint POST /api/remotes/<id_hex>/<cmd> with the cmd in the
    URL (matches regex up|down|stop|program). Returns 204 on success,
    400 on bad input, 404 if the remote is unknown.
    - include/orchestrator.h: command_from_str(const char*) i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
    [main.cpp, rf.cpp, test_main.cpp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]
2026-05-21 feat(iter 013): warn user about Somfy's 2-remote Erase workflow (#17)
    Discovered during iter 011 / 012 HW validation : Somfy receivers
    exclude the issuing remote from deletion candidates, so the 🗑 Erase
    button cannot be used to self-erase the remote it is on. The user
    must click Erase on a DIFFERENT already-paired remote, then brief
    Prog on the target. Without a UI hint, this is silent and confusing
    (motor jogs but nothing gets erased).
    Fix : add a native confirm() modal on the Erase click that names
    the clicked remote as SOURCE and reminds the user that the TARGET
    must be a different already-paired remote. OK proceeds, Cancel
    aborts. Same primitive as the existing delete-remote confirm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
    [web_ui.cpp]
2026-05-22 docs(iter 014): spec + architecture + plan for shutter position
    Add per-remote position tracking (0-100 %) by calibrating open / close
    times, and switch the MQTT layer to Tasmota's Shutter semantics keyed
    by remote name (instead of Tasmota's integer index). The bridge becomes
    directly consumable by any Tasmota-aware client.
    Key decisions :
    - NVS gains open_time_ms, close_time_ms, position per remote ; mqtt
    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
2026-05-22 feat(iter 014 step 1): shutter_state pure-logic estimator + tests
    Add `include/shutter_state.h` with three inline functions :
    - estimate() : linear position estimate from elapsed motion time,
    clamped to [0, 100], with defensive handling for clock skew and
    uncalibrated durations.
    - should_stop() : decides whether the orchestrator should send Stop
    given the live estimate vs target. Returns false for target 0 or
    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
2026-05-22 feat(iter 014 step 2): NVS extensions for shutter position + MQTT topic
    Extend the persistent store to back the iter 014 shutter position
    feature and the configurable Tasmota-style root topic.
    Schema bump 1 -> 2 : a board flashed with the new firmware on an
    existing iter 011/013 NVS layout will refuse to operate until
    factory_reset (accepted while we are in dev ; user agreed on the
    wipe-on-flash strategy).
    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
2026-05-22 feat(iter 014 step 3): MQTT Tasmota subset + position state machine
    Replace the legacy somfy2mqtt/<HEXID>/{set,state,rolling_code}
    topics with Tasmota's Shutter MQTT subset, keyed by remote name
    (not Tasmota's integer index -- names are already human-readable
    in our UI). Add per-remote time-based position tracking.
    MQTT topic structure (with <root> = mqtt.topic from NVS, default
    somfyrts2mqtt-<MAC>) :
    Subscribed (commands)
    cmnd/<root>/<name>/Open
    cmnd/<root>/<name>/Close
    cmnd/<root>/<name>/Stop
    cmnd/<root>/<name>/Position 0..100
    cmnd/<root>/<name>/OpenDuration <seconds float>
    cmnd/<root>/<name>/CloseDuration <seconds float>
    cmnd/<root>/<name>/Se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
    [main.cpp, test_main.cpp]
2026-05-22 feat(iter 014 step 6): web UI for topic, durations, position
    Final piece of iter 014 : surface the new shutter-position controls
    in the embedded web UI.
    MQTT section :
    - Add Topic field (alnum + _ + - + / regex). Empty = use the
    hostname-derived default. A subline below shows what root the
    bridge is currently using ("In use: somfyrts2mqtt-XXXXXX (auto,
    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
2026-05-22 feat(tools): mqtt-cli.py for testing the iter 014 MQTT API
    User-friendly Python CLI that exercises every verb the bridge
    publishes under the Tasmota Shutter subset (iter 014). One file,
    argparse subcommands, env-var or flag config, lazy paho-mqtt import
    (so --help works without the dep installed).
    Subcommands :
    open / close / stop <name>
    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
2026-05-22 fix(ui): wider page + scrollable Remotes table
    Iter 014 added three columns (Open, Close, Position) to the Remotes
    table, which overflow the previous 720 px page width -- the last
    Commands buttons (Pair, Erase, delete) were cropped off the right
    edge.
    - Bump body max-width to 1100 px : fits the full row on a desktop.
    - Wrap the Remotes table in a .table-wrap div with overflow-x: auto
    and a 720 px min-width so the table scrolls horizontally on
    narrower viewports rather than spilling out of the section.
    Build clean.
    [web_ui.cpp]
2026-05-22 feat(mqtt): default root topic 'somfyrts2mqtt' (no MAC suffix)
    The MAC-derived default (somfyrts2mqtt-XXXXXX) was unique per device
    but verbose in every CLI / log / mosquitto_sub line, even for the
    common single-bridge case. Switch the default to the plain name
    somfyrts2mqtt ; users who need multiple bridges on the same broker
    set distinct topics via the web UI (the client_id is derived from
    the topic so two bridges with the same topic would kick each other
    on connect).
    Touched :
    - src/mqtt.cpp : compute_default_root returns "somfyrts2mqtt".
    Comment notes the multi-bridge migration path.
    - src/web_ui.cpp : drop the "auto, derived from hostname" hint ;
    update the Topic input title to exp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
    [web_ui.cpp]
2026-05-22 feat(iter 014): per-remote invert flag (Up/Down swap for awnings)
    A Somfy RTS awning ("store banne") is paired with the motor so that
    the Up physical button retracts the awning (user-perceived "close")
    and the Down button extends it (user-perceived "open"). Without an
    invert flag, our Open / Close commands move the awning in the wrong
    direction.
    Add a per-remote `invert` flag :
    - nvs_store::Remote gains `bool invert` ; NVS key `r.<HEXID>.inv`.
    - nvs_store::set_invert(id, bool) persists the value.
    - Orchestrator swaps Up <-> Down at the RF emission layer when
    invert is true. The runtime state machine (Position, Direction,
    Target) stays in user space : 100 = open / extended regardless.
    -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
    [web_ui.cpp]
2026-05-22 feat(ui): split Remotes table into operational row + Setup panel
    The Commands cell mixed daily operations (Up/Stop/Down) with rare and
    dangerous pairing actions (Prog/Pair/Erase), and the Calibration column
    inputs (Open/Close durations + Invert toggle) were always visible even
    though they are set once per remote and never touched again.
    Reorganization:
    - Main row keeps only Up/Stop/Down + Move-to-% + a ⚙ button.
    - A per-row Setup panel (display:none by default) is expanded via ⚙
    and groups Calibration (Open/Close durations, Invert checkbox, Sync
    button) and Pairing (Prog/Pair/Erase). Expanded state survives the
    1 Hz refresh during motion via a Set captured at the top of
    loadRemo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
    [web_ui.cpp]
2026-05-22 fix(wifi): TX power 13 dBm to bypass C3 Super Mini PA saturation (#20)
    * fix(wifi): set TX power to 13 dBm to bypass C3 Super Mini PA saturation
    The ESP32-C3 Super Mini boards have a miscalibrated power amplifier
    that saturates above ~15 dBm on some boards. The default TX power
    (~19.5 dBm) sends corrupted RF on those boards, the WPA2 4-way
    handshake never completes, and the AP times out the auth state
    (AUTH_EXPIRE loop, reason 2).
    Empirical sweep across multiple boards :
    - board A : connects at every level up to 19.5 dBm
    - board B : connects up to 15 dBm, fails above
    Setting 13 dBm explicitly via WiFi.setTxPower() right after
    WiFi.mode(WIFI_STA) is a safe upper bound :
    - well below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
2026-05-22 feat(iter 015): WiFi captive portal commissioning (Tasmota-style) (#19)
    * docs(iter 015): spec + architecture + plan for WiFi captive portal
    Tasmota-style WIFI_RETRY default: AP only on (1) NVS without creds, or
    (2) 4 rapid power-cycles tracked by an NVS boot counter that resets after
    5 s of stable uptime. Runtime STA drops keep retrying forever -- never
    fallback to AP, to preserve remote LAN access on routine network blips.
    In-LAN reconfiguration via a WiFi form in the admin UI (POST /api/wifi);
    inaccessible-box recovery via the 4 power-cycles -- no GPIO button, no
    serial console, no factory reset required.
    Captive portal UI delegated to tzapu/WiFiManager (MIT, drop-in) to avoid
    re-imple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
    [main.cpp, test_main.cpp, web_ui.cpp]
2026-05-22 docs: full README + docs/ folder with screenshots (#21)
    Add user-facing documentation. README is the entry point ; docs/ holds
    the deep-dive pages, organised by user journey :
    - docs/hardware.md : BoM, ESP32-C3 / WROOM pinout for the CC1101,
    antenna and PSU notes
    - docs/setup.md : build, first flash, captive portal commissioning,
    MQTT broker config, adding remotes, calibration,
    factory reset, 4-power-cycle recovery
    - docs/web-ui.md : section-by-section walkthrough of the admin UI
    with embedded screenshots
    - docs/mqtt-api.md : Tasmota Shutter topic reference, paylo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
2026-05-23 docs(meca): integrate enclosure (FreeCAD + STLs + photo) (#25)
    * docs(meca): integrate enclosure (FreeCAD + STLs + photo)
    The newly-committed meca/ directory ships a 3D-printable housing
    for the bridge (ESP32 + CC1101 + SMA antenna + USB-C cable in a
    compact box with a bolt-on cover). Surface it in the user-facing
    docs so anyone landing on the README sees that this is a real,
    finished thing -- not just a breadboard project.
    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
    [somfyrts2mqtt_housing-box_cover.stl, somfyrts2mqtt_housing-box_housing.stl, somfyrts2mqtt_housing.FCStd]
2026-05-23 docs(readme): better Sowel + Tasmota framing, mention wire-wrap (#26)
    Two intro tweaks based on author feedback :
    1. Replace the bare GitHub link to Sowel with a richer paragraph
    that anchors the bridge on the Tasmota Shutter MQTT protocol it
    actually speaks. Lists the integration paths : Sowel via the
    sowel-plugin-somfy-rts plugin (the original target), Home
    Assistant via MQTT Cover, OpenHAB / Node-RED / custom MQTT
    clients. Links go to docs.sowel.org and to the plugin repo
    rather than to the Sowel app repo.
    2. The "few minutes of soldering" line now mentions wire-wrapping
    as the author's preferred interconnect for the compact
    ESP32 <-> CC1101 link inside the housi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
2026-05-23 docs(meca): drop SMA pigtail + whip antenna from mech BoM (#27)
    Both ship with most CC1101 modules, so listing them as extra parts
    to source was misleading. Replaced the rows with a one-line note
    about the housing notch for the SMA flange.
2026-05-23 feat(mqtt): retain SENSOR + add bridge-wide Status cmnd (iter 017) (#28)
    A subscriber connecting to the broker after the bridge boot used to
    receive nothing on tele/<root>/SENSOR until something moved — which
    broke discovery for the Sowel sowel-plugin-somfy-rts integration on a
    quiet morning.
    - publish_sensor_aggregated() now publishes with retained=true. Every
    call site (connect, periodic, on cmnd, on calibration) inherits the
    fix; new subscribers get the snapshot immediately on subscribe.
    - New cmnd/<root>/Status topic (3-segment, parallel to the existing
    4-segment cmnd/<root>/+/+) forces a fresh SENSOR publish on demand.
    Tasmota-style naming.
    - docs/mqtt-api.md updated: SENSOR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
2026-05-26 feat(wifi): replace tzapu with Sowel-styled captive portal (spec 018) (#29)
    Drop tzapu/WiFiManager and replace it with our own AP + DNSServer +
    AsyncWebServer captive portal, modeled on sowel-energy-display/src/portal.cpp.
    First-run UX now visually matches the rest of the Sowel device family: same
    SOWEL brand header, same light palette (#1A4F6E / #E6F0F6 / #D4963F /
    #F8F9FA / #FFFFFF / #1A2A3C), same system font stack (no Google Fonts —
    the phone is offline once joined to the AP), same .card / .field /
    .with-toggle / .btn DOM scaffold, same inline-SVG eye toggle for the
    password field.
    Bridge-specific narrowing: only WiFi creds (SSID dropdown from
    WiFi.scanNetworks + password) are collect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
2026-05-26 feat(web): align LAN portal with Sowel light design (spec 019) (#30)
    * feat(web): align LAN portal with Sowel light design (spec 019)
    Replace the dark generic theme of the LAN web portal (web_ui.cpp,
    http://<bridge-ip>/) with the same Sowel light palette + DOM vocabulary
    the spec-018 captive portal uses. The two pages now feel like a single
    product surface: same SOWEL brand header + tagline, same primary blue,
    same primary-light focus rings, same card / form / pill / button
    treatment, same system font stack.
    Scope:
    - Replace the <style> block of INDEX_HTML in src/web_ui.cpp. Restyle
    every existing class without touching the markup or the JS: .kv,
    .cards-row, .row, .pass-wrap, .eye (+ o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
    [web_ui.cpp]
2026-05-26 chore: drop ESP32 WROOM board (spec 020) (#31)
    Scope reduction to the C3 Super Mini, the only board ever shipped in
    practice. The WROOM env was carried since the multi-board iter (spec
    008) but never used; it doubled CI build time and diluted the docs
    with a variant no longer maintained.
    Active code paths:
    - platformio.ini: remove [env:esp32-wroom] block.
    - .github/workflows/ci.yml: single-env build (no matrix).
    - .github/workflows/release.yml: one firmware build + one bin artifact
    (was two). Body text and install instructions updated accordingly.
    - include/config.h: drop the WROOM CC1101 pinout (#elif
    CONFIG_IDF_TARGET_ESP32). The #error fallback now points to the C3
    as the only supp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
2026-07-09 feat(build): add ESP32-S3 PICYBI board + per-variant OTA safety (spec 021) (#35)
    * feat(build): add ESP32-S3 PICYBI board + per-variant OTA safety
    Add the ESP32-S3 "PICYBI Radio Remote" as a second supported board (its
    own CC1101 pinout + [env:esp32-s3-picybi]) and make the build/release/OTA
    pipeline safe now that binaries are not interchangeable across chips
    (RISC-V C3 vs Xtensa S3, different pinout):
    - include/ota_guard.h: pure, native-tested esp_image_header chip_id
    parser. The WebOTA handler rejects an image built for another chip on
    the first chunk (HTTP 400, before any flash write) with a clear
    message, instead of the otherwise-silent bootloader rollback on reboot.
    - FW_VARIANT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
    [main.cpp, test_main.cpp, web_ui.cpp]
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
